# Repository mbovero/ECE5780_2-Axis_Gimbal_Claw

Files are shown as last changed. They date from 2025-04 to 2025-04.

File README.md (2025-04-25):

Demo

### Team Members
* Miles Bovero
* Lawrence Ponce
* Brian Stites
* Burke Dambly
  
# 2-Axis Gimbal System using BNO085 and TMC2209

This project implements a 2-axis gimbal system powered by NEMA 17 stepper motors, a custom TMC2209 stepper driver, and the BNO085 IMU, all controlled by an STM32F0 microcontroller. The system supports both **manual joystick control** and **automatic gimbal stabilization** using quaternion feedback from the IMU.

## Features

- **Automatic stabilization** using BNO085 quaternion output (Rotation Vector).
- **Manual override mode** via joystick input.
- **Custom driver logic** for TMC2209 stepper controllers (no libraries).
- **Status indication** using onboard LEDs:
  - 🟢 **Green**: System ready
  - 🟡 **Yellow**: Manual mode
  - 🔴 **Red**: Gimbal stabilization mode

## Hardware

- **Parts List:** https://docs.google.com/spreadsheets/d/1ASUmAiZSFDpc-IezaZOCM-j6GSmX4DIoBAKoNAnrK8I/edit?gid=0#gid=0
- **BOM:** https://docs.google.com/spreadsheets/d/1F1Fa0VNCSiJDzJphaV6HfyEmqR7Gyjhc7J4WnCEqq48/edit?usp=sharing

## Control Logic

- System starts in **gimbal mode**. The initial orientation is stored as the target.
- A joystick button press toggles between **manual** and **gimbal** mode.
- In **manual mode**, the joystick directly sets direction and speed of the motors.
- In **gimbal mode**, real-time quaternion feedback from the IMU drives motors to minimize roll and yaw error.
- The STM32 blue on-board button acts as a **kill switch**, freezing the system until reset.

## Project Structure

- `main.c` – Main call to control function.
- `bno085.c/h` – IMU I2C interface and quaternion parsing logic.
- `motor_control.c/h` – Low-level motor driver setup and PWM control.
- `quaternion.c/h` – Roll and yaw error computation from quaternion deltas.
- `gimbal_controller.c/h` – Core application logic for managing gimbal behavior, mode switching, LED indicators, and overall control flow between manual and automatic stabilization.
- `joystick.c/h` – ADC interface for reading joystick analog input.

## Flow Chart
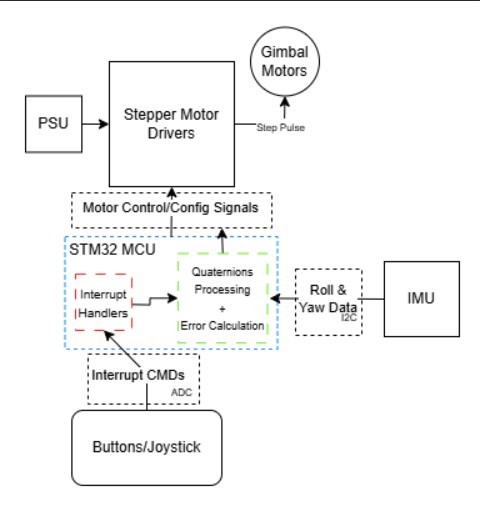
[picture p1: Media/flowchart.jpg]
Functional Diagram


## Capabilities

- Real-time stabilization on **roll and yaw axes** using quaternion feedback from the BNO085 IMU.
- Responsive **manual control** through a 2-axis joystick.
- Intelligent speed scaling and jitter prevention based on calculated orientation error.
- Mode switching with software debouncing: easily toggle between manual and gimbal modes.
- Visual mode indication via red (manual) and yellow (gimbal) LEDs, and a green LED for system readiness.
- **Kill switch functionality** to safely disable the system at any time.

### Limitations

- The current mechanical setup limits **full-range roll rotation**. Due to the gimbal frame geometry, the roll axis cannot rotate completely while maintatining yaw logic without mechanical interference.
- All quaternion math is handled using **fixed-point arithmetic**, which prioritizes performance on the STM32F0 but limits precision.

## Setup

1. **Wiring:**
   - **Wiring Diagram:** https://drive.google.com/file/d/1Tr6oJw9C9LlnuBq3UyTGPtjXQ-eJ-zLg/view?usp=sharing
   - See Wiring section below for more details

2. **Flashing:**
   - Use Platformio in VS Code to Flash board.
   - Run `platformio run -e gimbal_controller -t upload` in the Platformio terminal.

3. **Start Sequence:**
   - Wait for the **green LED** to turn on (IMU ready).
   - Press joystick button to toggle modes.
   - Use the kill switch (blue STM USER button) to halt the system if needed.

## 🔌 Wiring Connections
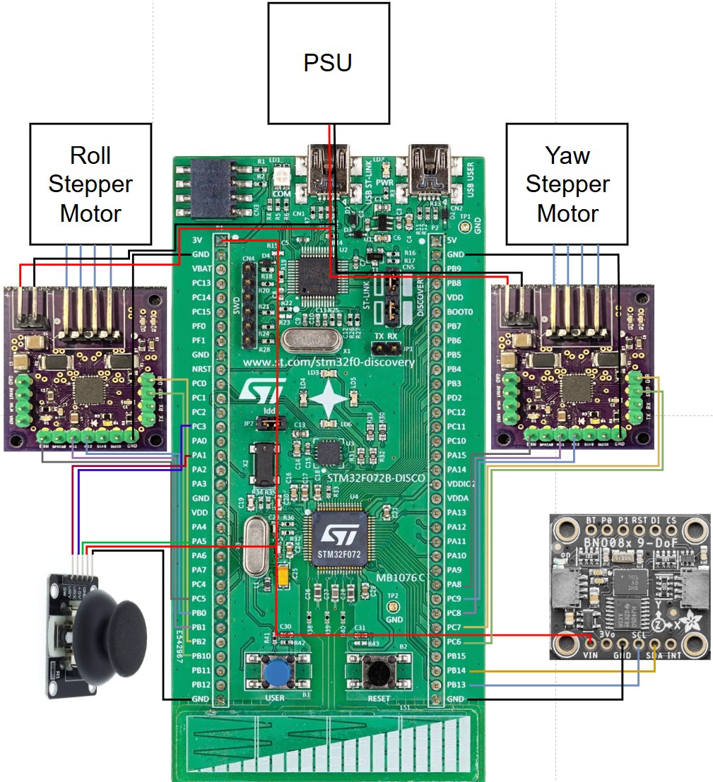
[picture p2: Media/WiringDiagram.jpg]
Wiring Diagram


### STM32 → IMU Wiring

| STM32 Pin | IMU Pin |
|---|---|
| 3V | 3V3 |
| GND | GND |
| PB14 | SDA / RX |
| PB13 | SCL / TX |

### STM32 → Motor Driver Wiring

#### YAW Motor Driver

| STM32 Pin | Motor Driver Pin |
|---|---|
| PC6 | STEP |
| PC7 | DIR |
| PC8 | MS1 |
| PC9 | MS2 |
| PA8 | ENN |
| GND | GND |

#### ROLL Motor Driver

| STM32 Pin | Motor Driver Pin |
|---|---|
| PB10 | STEP |
| PB2 | DIR |
| PB1 | MS1 |
| PB0 | MS2 |
| PC5 | ENN |
| GND | GND |

### STM32 → Joystick Wiring

| STM32 Pin | Joystick Pin |
|---|---|
| PC3 | VRY |
| PA5 | VRX |
| PA1 | SW |
| 3V | 5V |
| GND | GND |

### STM32 → LED Wiring

| STM32 Pin | Function |
|---|---|
| PB3 | IMU status LED |
| PB4 | Manual mode indicator LED  |
| PB5 | Gimbal mode indicator LED  |

## Notes
- Quaternion values are in **Q14 format** and processed using fixed-point arithmetic to avoid floating-point dependency.

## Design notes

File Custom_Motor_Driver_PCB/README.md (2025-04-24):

# PCB Layout Preview
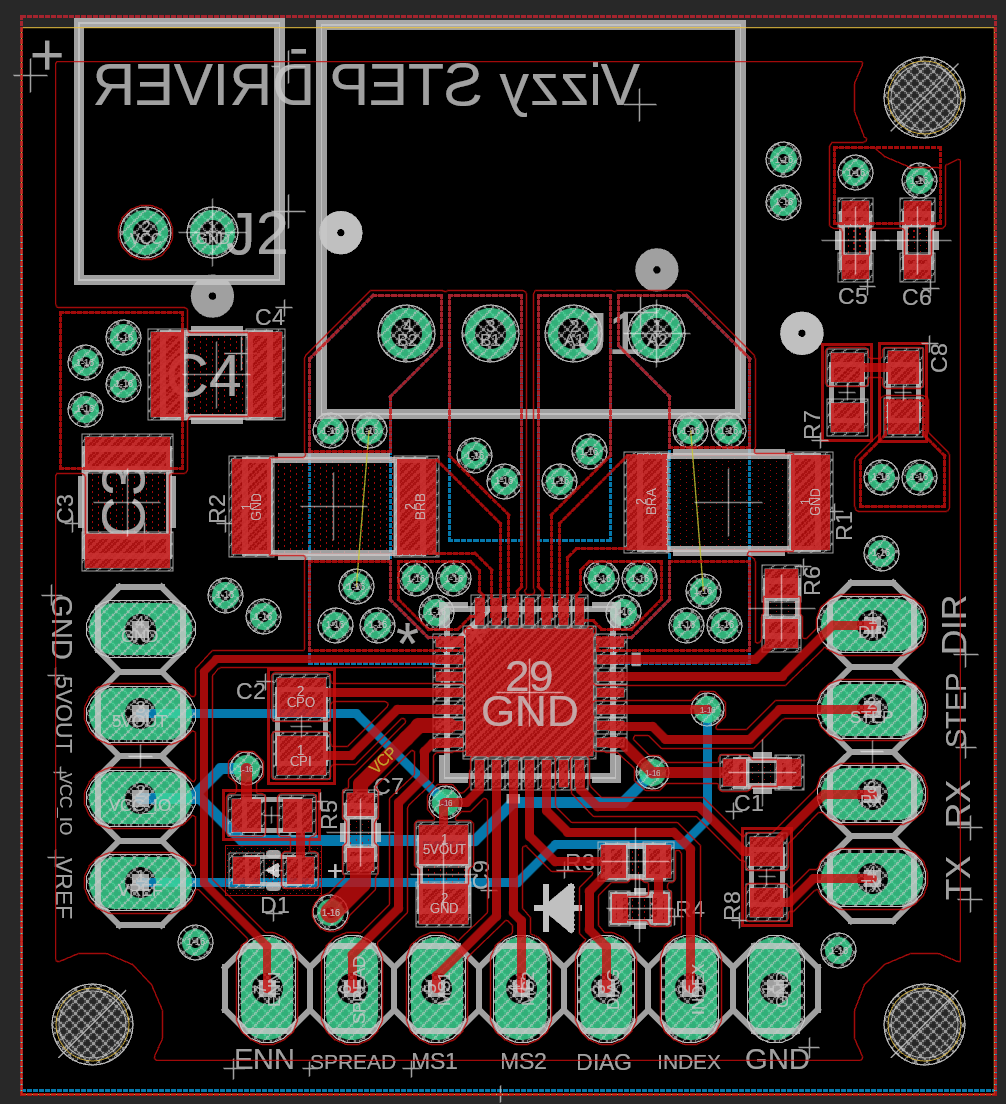
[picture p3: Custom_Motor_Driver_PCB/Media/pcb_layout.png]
PCB Layout Preview


# Circuit Schematic
[Circuit Schematic (PDF)](Media/circuit_schematic.pdf)

# 3D PCB Layout Preview
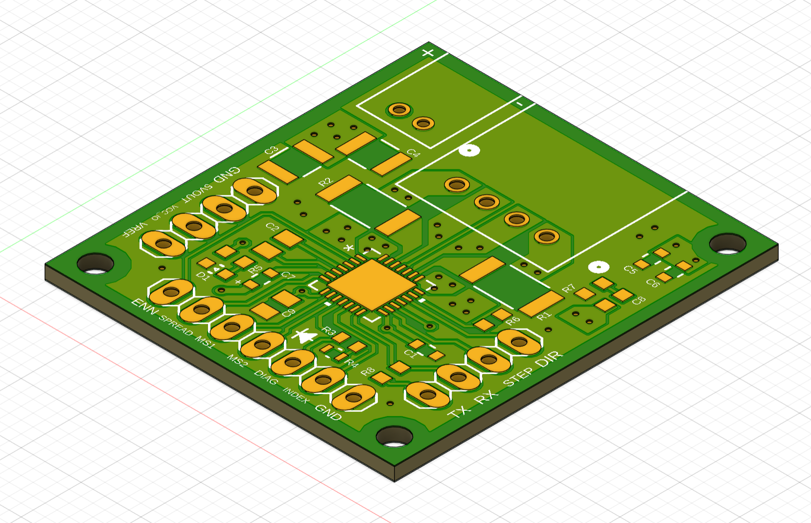
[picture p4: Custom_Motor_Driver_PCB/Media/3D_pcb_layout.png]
3D_PCB Layout Preview


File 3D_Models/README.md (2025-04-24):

# Upper Assembly Preview
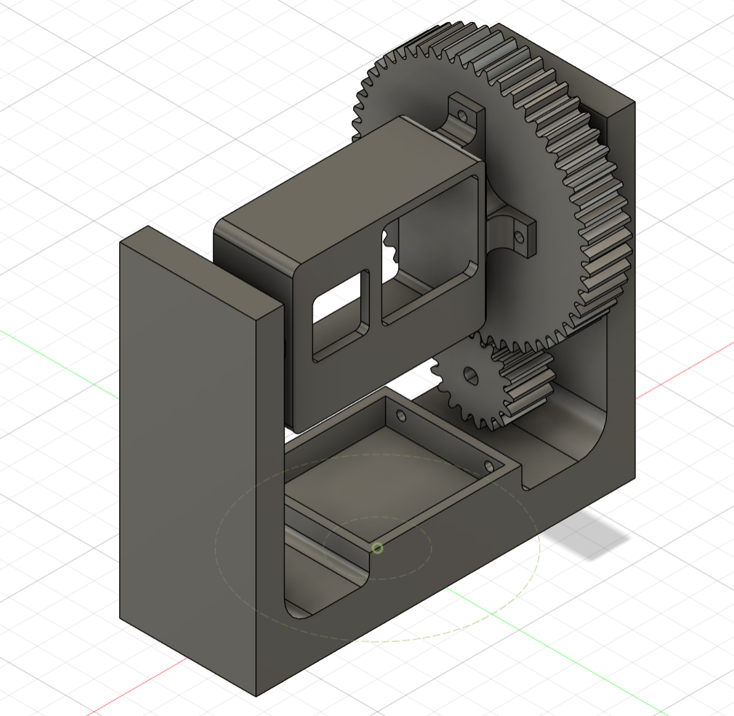
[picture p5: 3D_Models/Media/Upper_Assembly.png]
Upper Assembly


# Joystick Cage Preview
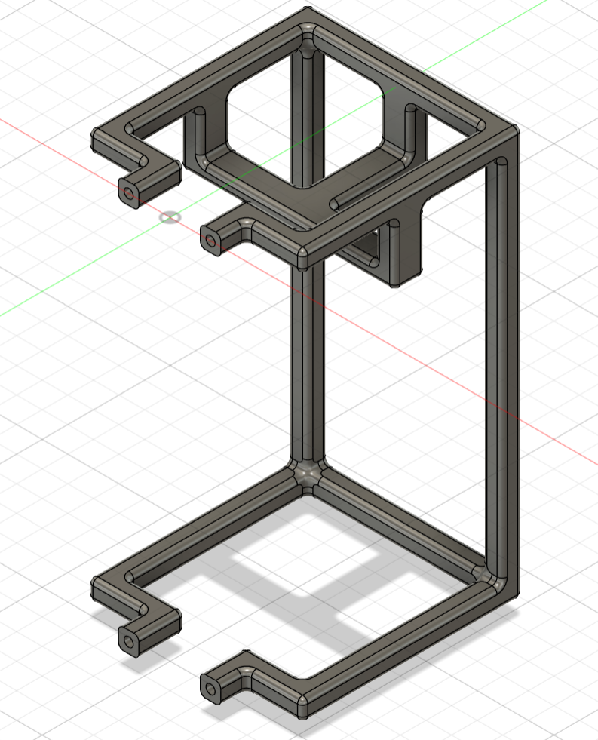
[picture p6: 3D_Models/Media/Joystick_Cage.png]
Joystick Cage


# Handle Preview
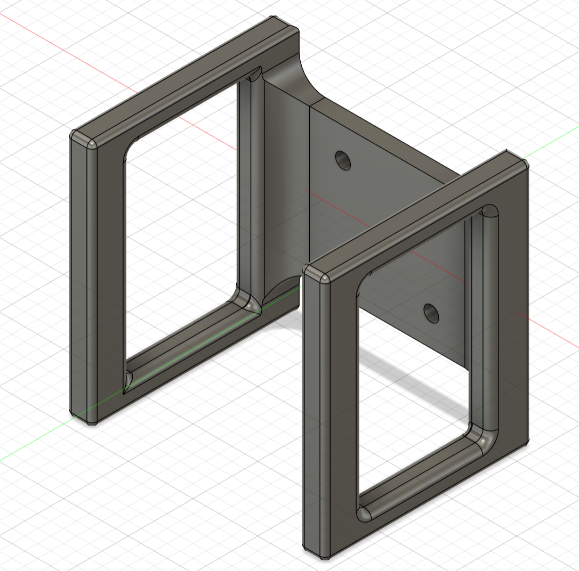
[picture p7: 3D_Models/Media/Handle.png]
Handle


# Gimbal Base Preview
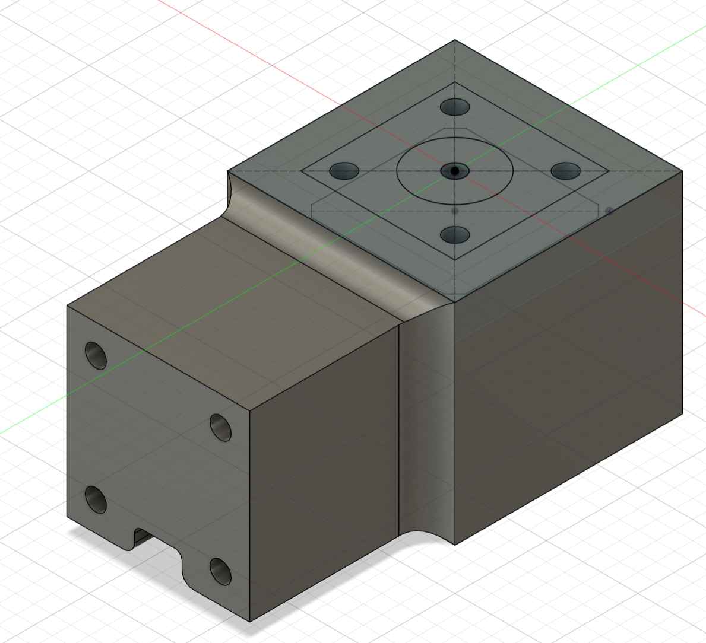
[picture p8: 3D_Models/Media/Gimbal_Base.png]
Gimbal_Base


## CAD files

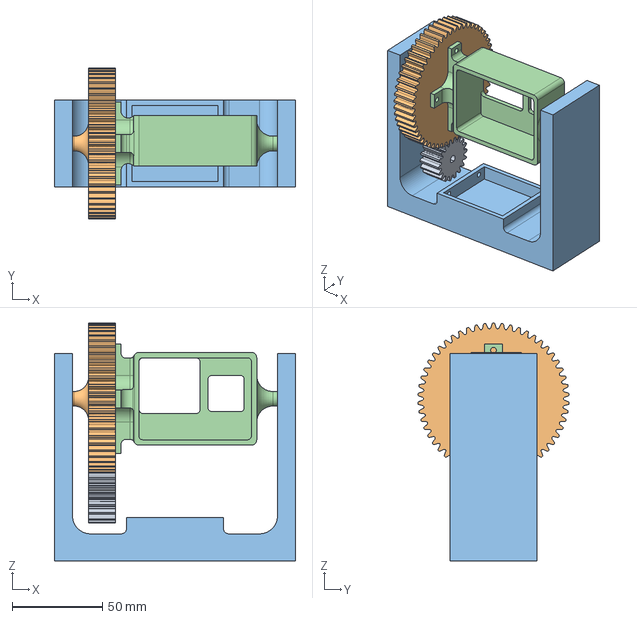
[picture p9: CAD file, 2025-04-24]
3D_Models/Upper Assembly v18.step
133.8 x 83.9 x 132.0 mm
Spur Gear (18 teeth)
Spur Gear (54 teeth)

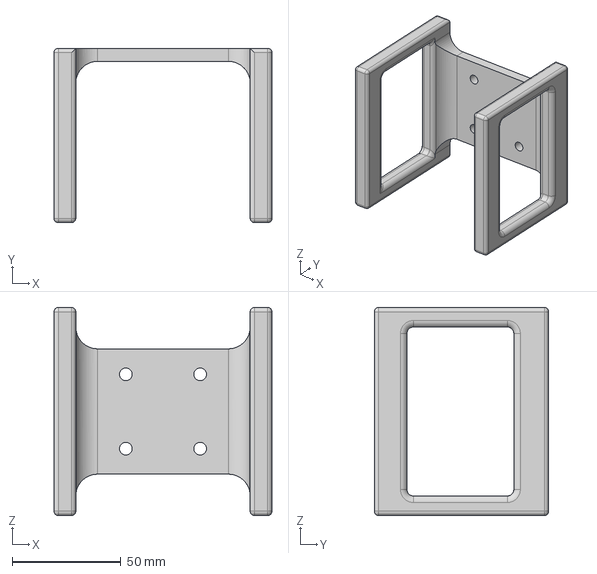
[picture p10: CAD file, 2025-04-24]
3D_Models/handle v4.step
100.0 x 80.0 x 95.5 mm

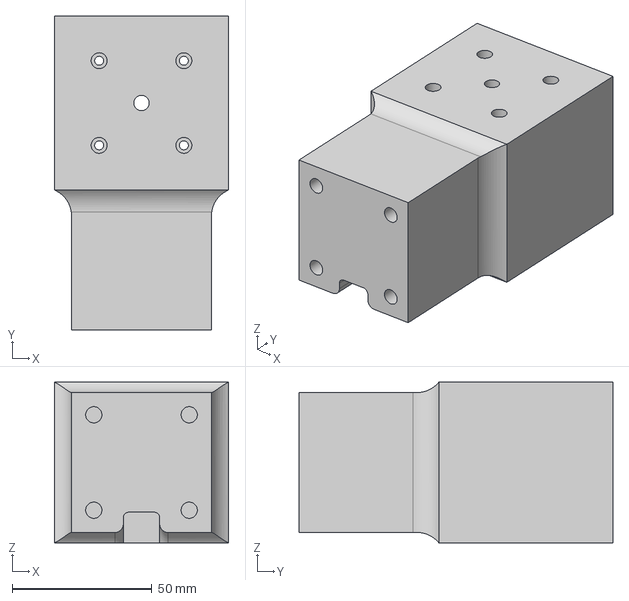
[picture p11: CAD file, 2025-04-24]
3D_Models/Gimbal Base v8.step
62.2 x 112.2 x 57.5 mm

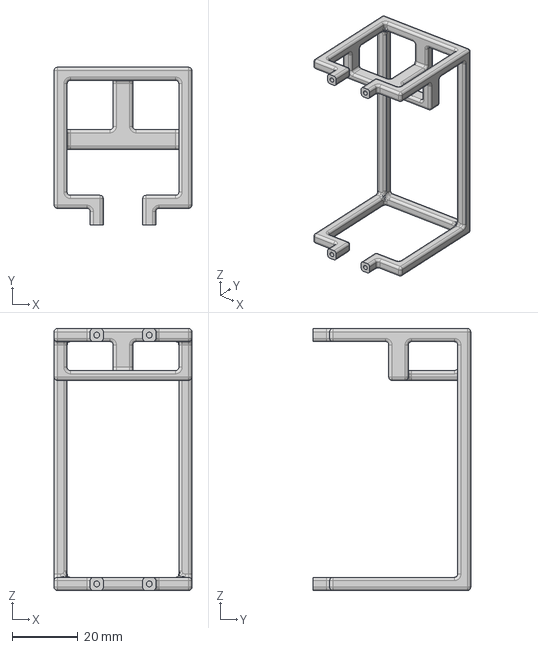
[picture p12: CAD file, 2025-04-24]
3D_Models/Joystick cage v3.step
42.0 x 48.0 x 79.8 mm

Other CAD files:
Custom_Motor_Driver_PCB/TMC2209_Circuit v29.f3z

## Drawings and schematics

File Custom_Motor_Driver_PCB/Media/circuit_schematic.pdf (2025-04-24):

GND | PINHD⁻¹X⁰⁷_1X⁰⁷M | PINHD⁻¹X⁰⁴_1X⁰⁴M
R8 | C9 J2

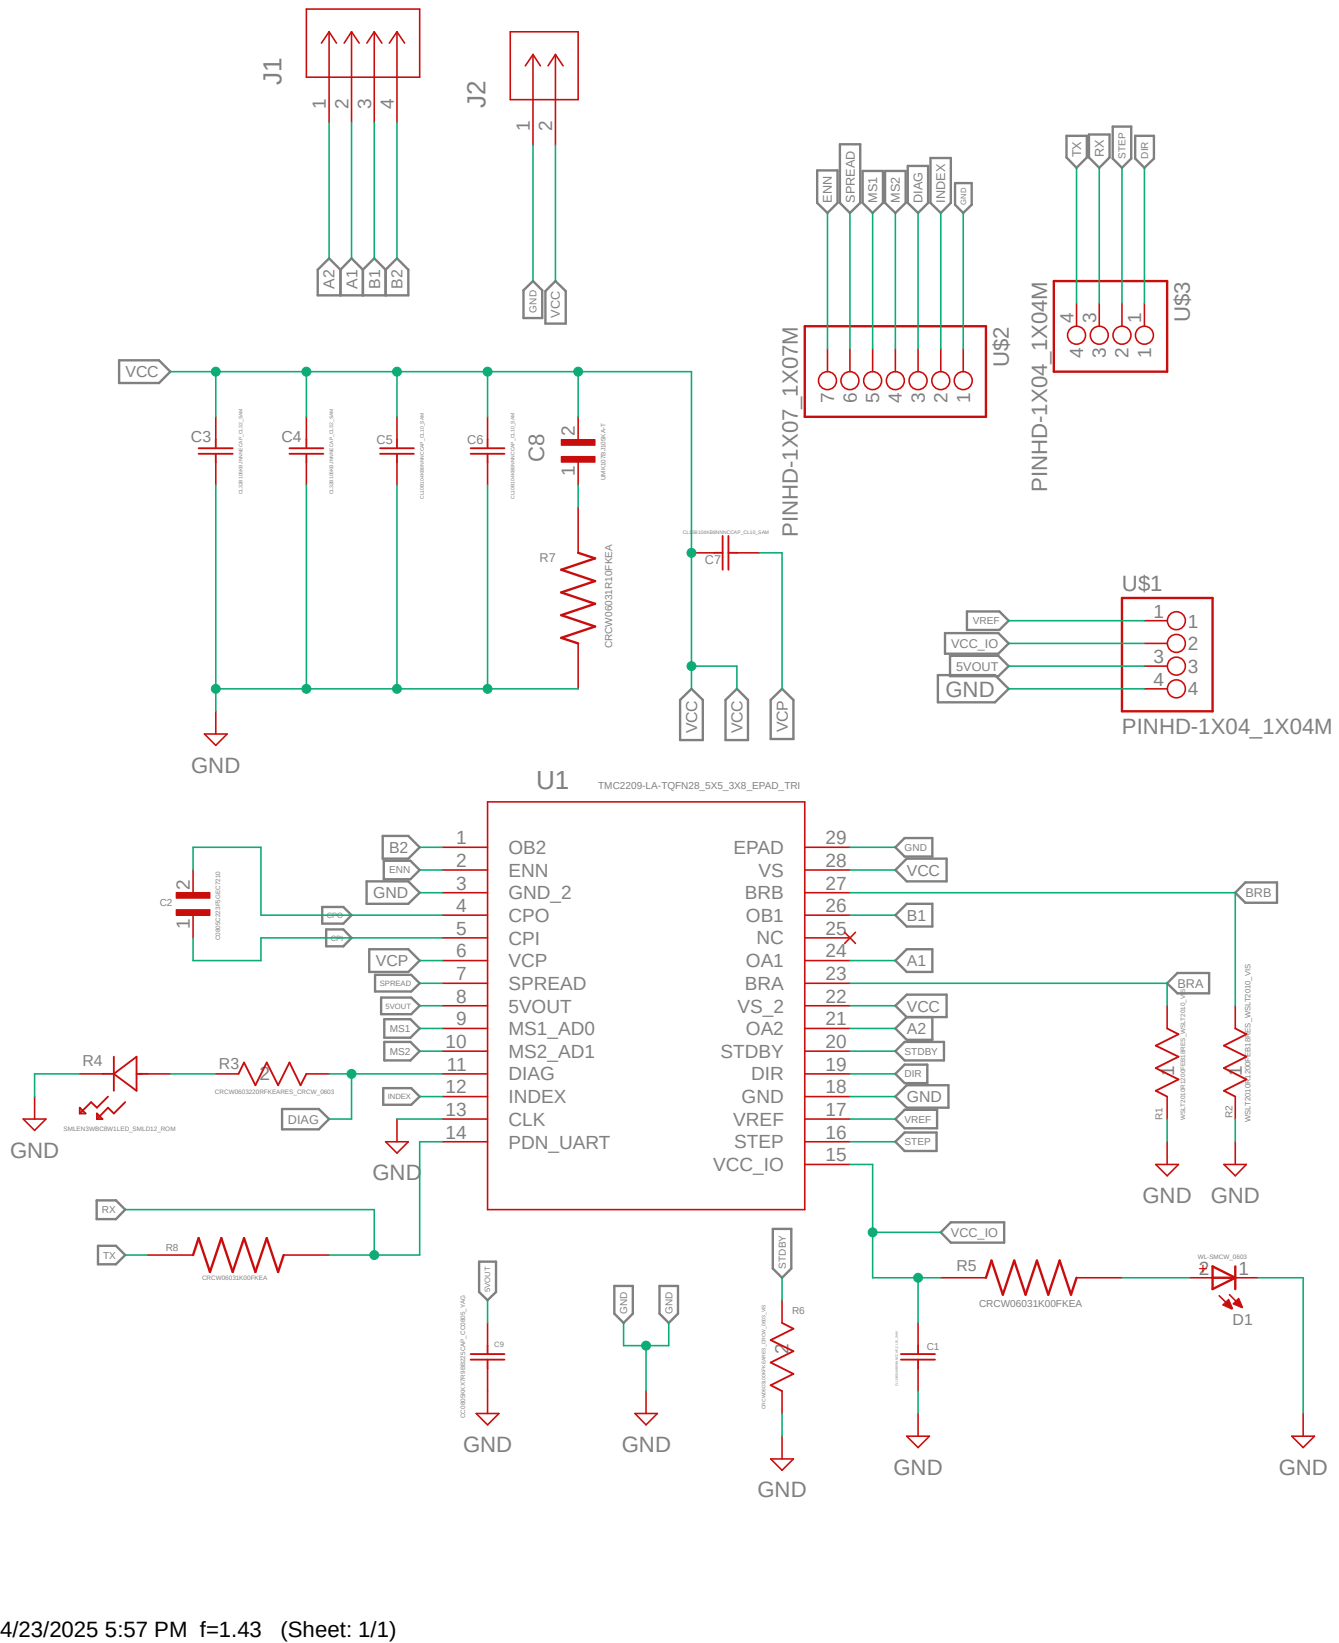
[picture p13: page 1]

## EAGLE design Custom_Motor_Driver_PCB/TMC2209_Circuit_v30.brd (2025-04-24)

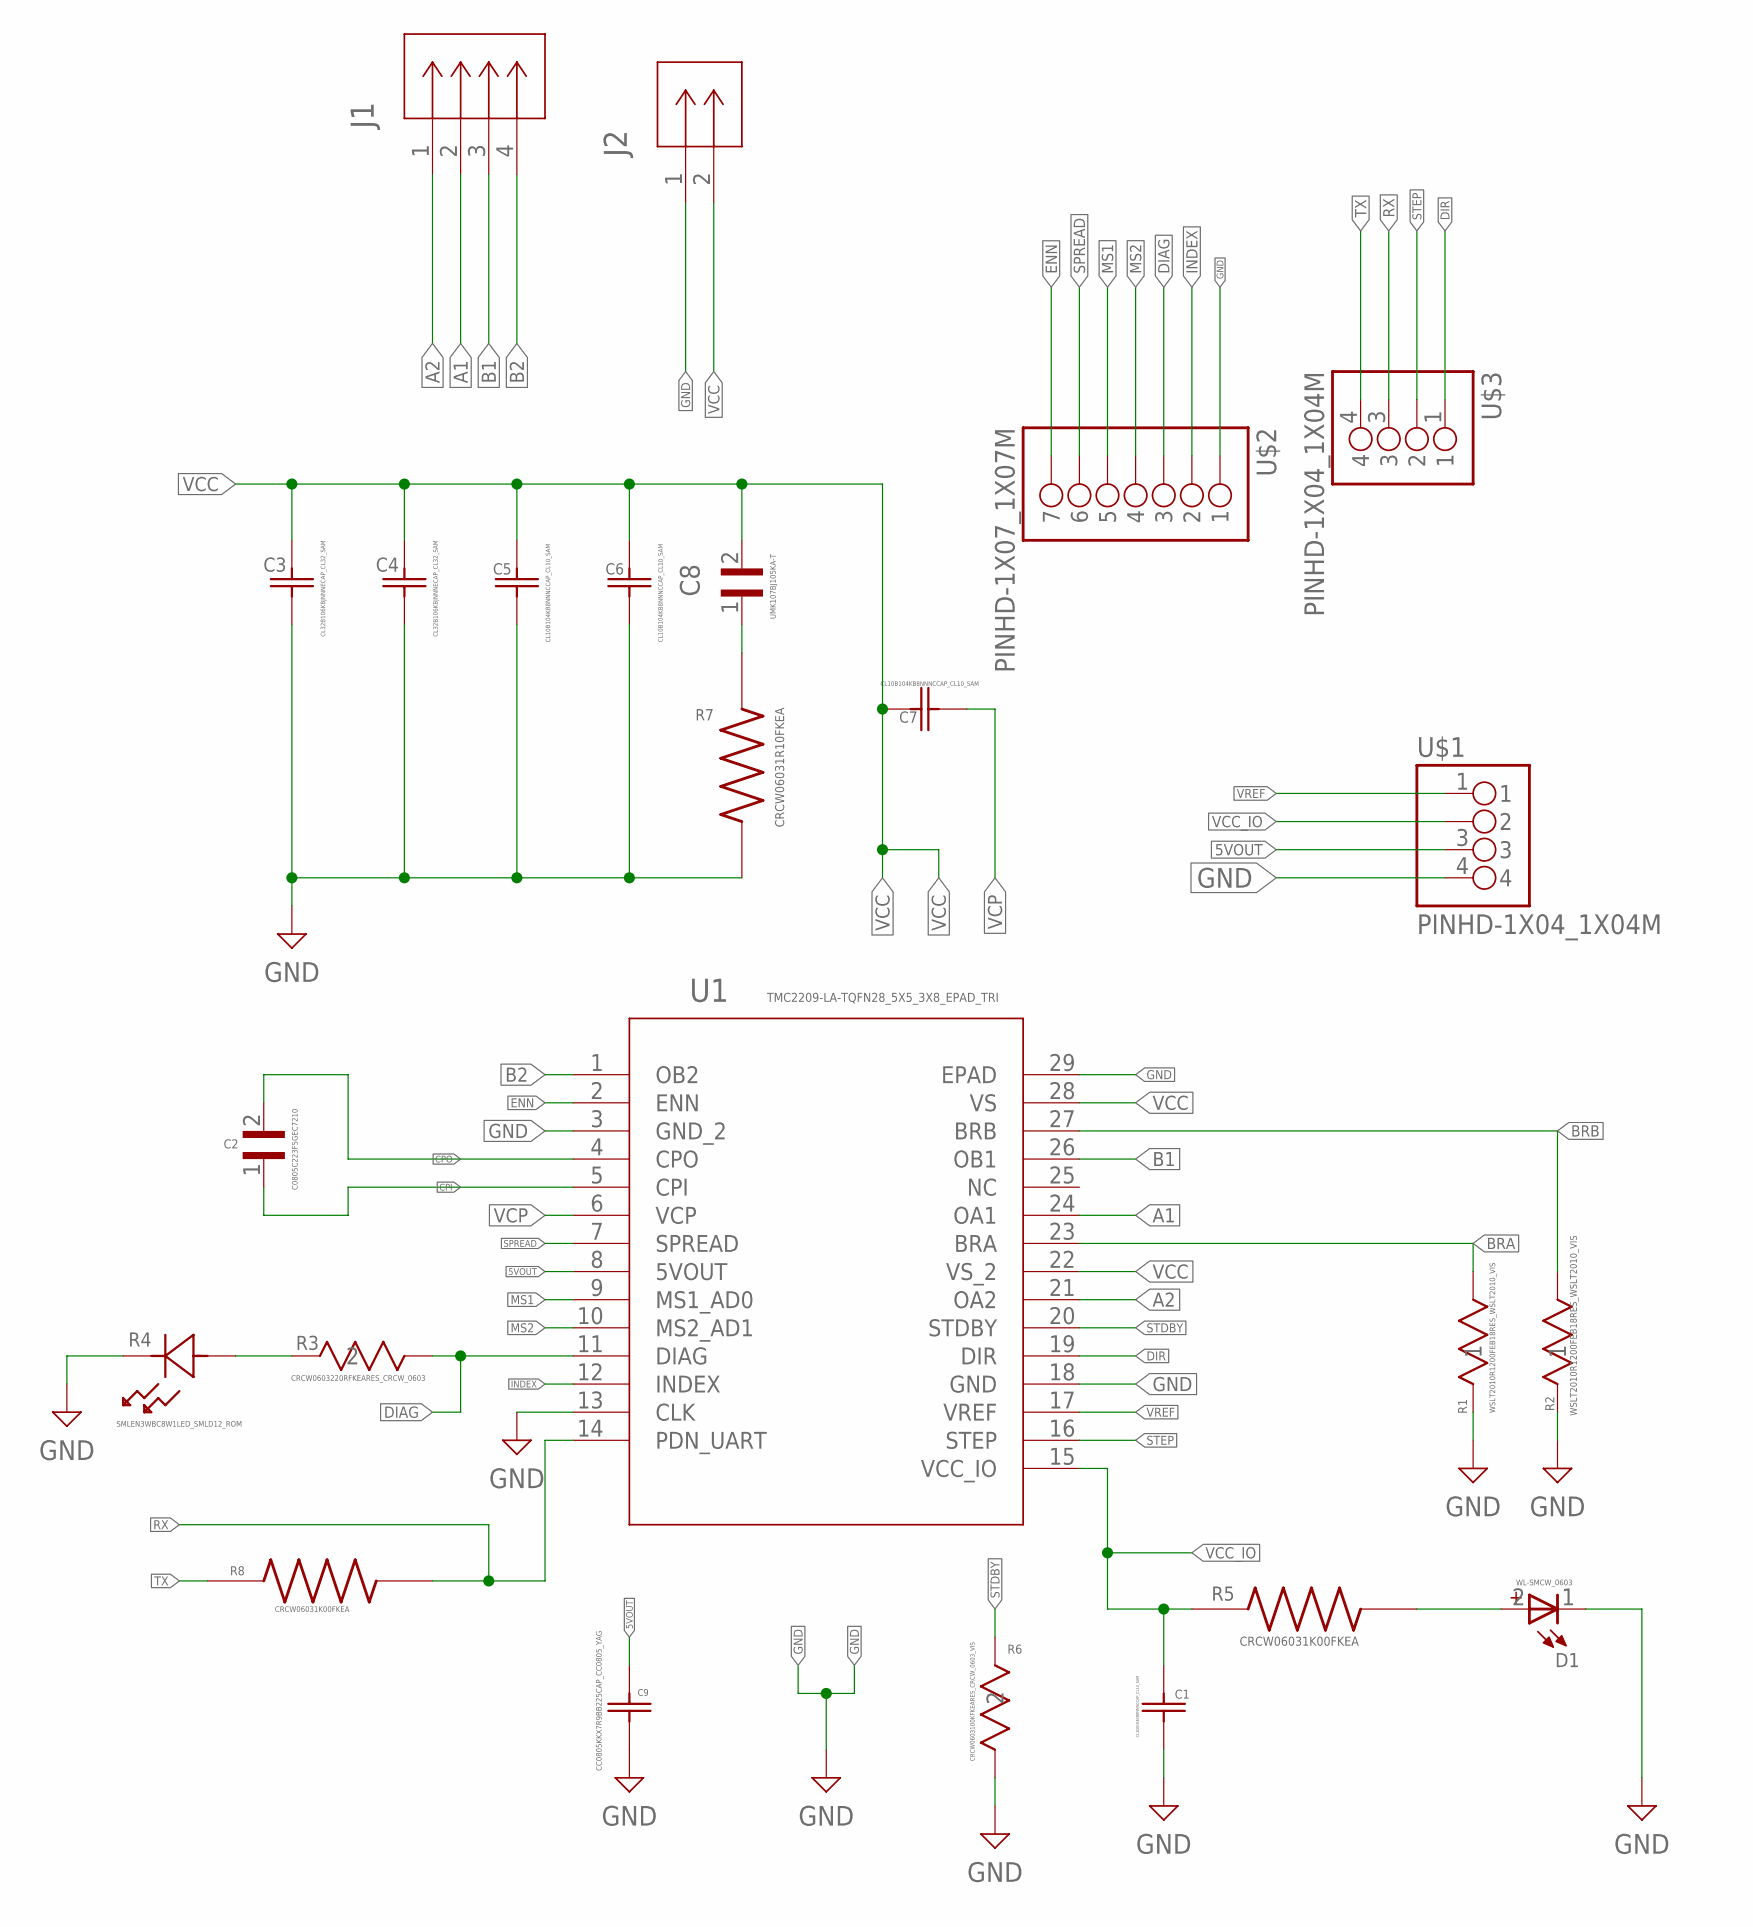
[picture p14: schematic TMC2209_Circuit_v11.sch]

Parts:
C1, C5, C6, C7: CL10B104KB8NNNCCAP_CL10_SAM; CAP_CL10_SAM
C2: C0805C223F5GEC7210; CAPC2012X120N
C3, C4: CL32B106KBJNNNECAP_CL32_SAM; CAP_CL32_SAM
C8: UMK107BJ105KA-T; CAPC1608X90N
C9: CC0805KKX7R9BB225CAP_CC0805_YAG; CAP_CC0805_YAG
D1: WL-SMCW_0603
J1: S4B-XH-A(LF)(SN)CONN_S4B-XH-A(LF)(SN)_JST; CONN_S4B-XH-A(LF)(SN)_JST
J2: S2B-PH-K-S(LF)(SN)CONN_S2B-PH-K-S_JST; CONN_S2B-PH-K-S_JST
R1, R2: WSLT2010R1200FEB18RES_WSLT2010_VIS; RES_WSLT2010_VIS
R3: CRCW0603220RFKEARES_CRCW_0603; RES_CRCW_0603
R4: SMLEN3WBC8W1LED_SMLD12_ROM; LED_SMLD12_ROM
R5, R8: CRCW06031K00FKEA; RESC1508X50N
R6: CRCW0603100KFKEARES_CRCW_0603_VIS; RES_CRCW_0603_VIS
R7: CRCW06031R10FKEA; RESC1508X50N
U1: TMC2209-LA-TQFN28_5X5_3X8_EPAD_TRI; QFN28_5X5_3X8_EPAD_TRI
U$1, U$3: PINHD-1X04_1X04M; 1X04
U$2: PINHD-1X07_1X07M; 1X07

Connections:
5VOUT: C9.1, U1.8 (5VOUT), U$1.3
A1: J1.2, U1.24 (OA1)
A2: J1.1, U1.21 (OA2)
B1: J1.3, U1.26 (OB1)
B2: J1.4, U1.1 (OB2)
BRA: R1.2, U1.23 (BRA)
BRB: R2.2, U1.27 (BRB)
CPI: C2.1, U1.5 (CPI)
CPO: C2.2, U1.4 (CPO)
DIAG: R3.1, U1.11 (DIAG), U$2.3
DIR: U1.19 (DIR), U$3.1
ENN: U1.2 (ENN), U$2.7
GND: C1.2, C3.1, C4.1, C5.1, C6.1, C9.2, D1.1 (-), J2.1, R1.1, R2.1, R4.1, R6.1, R7.1, U1.3 (GND_2), U1.13 (CLK), U1.18 (GND), U1.29 (EPAD), U$1.4, U$2.1
INDEX: U1.12 (INDEX), U$2.2
MS1: U1.9 (MS1_AD0), U$2.5
MS2: U1.10 (MS2_AD1), U$2.4
unnamed: R3.2, R4.2
unnamed: D1.2 (+), R5.2
unnamed: C8.1, R7.2
RX: R8.2, U1.14 (PDN_UART), U$3.3
SPREAD: U1.7 (SPREAD), U$2.6
STDBY: R6.2, U1.20 (STDBY)
STEP: U1.16 (STEP), U$3.2
TX: R8.1, U$3.4
VCC: C3.2, C4.2, C5.2, C6.2, C7.2, C8.2, J2.2, U1.22 (VS_2), U1.28 (VS)
VCC_IO: C1.1, R5.1, U1.15 (VCC_IO), U$1.2
VCP: C7.1, U1.6 (VCP)
VREF: U1.17 (VREF), U$1.1

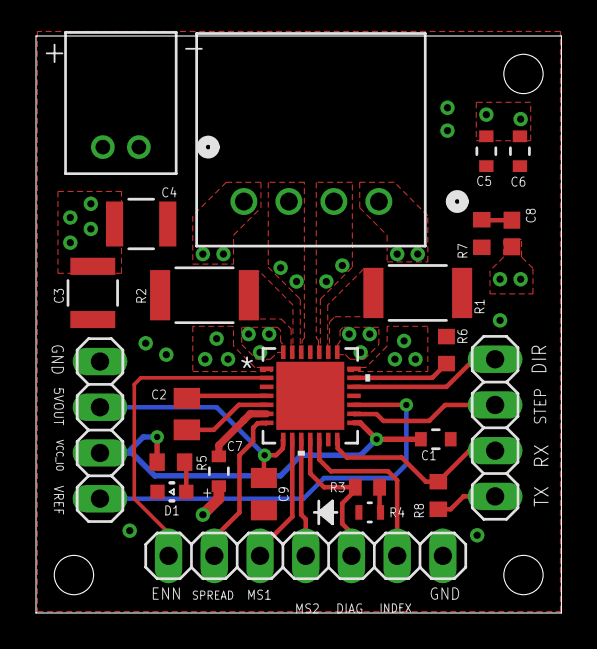
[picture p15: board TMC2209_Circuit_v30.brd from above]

Board: 4 copper layers, 29.2 x 32.1 mm, 24 parts (0 on the bottom side), 28 nets.

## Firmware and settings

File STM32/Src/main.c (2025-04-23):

#include "main.h"
#include <stm32f0xx_hal.h>

/**
 * Command  $ platformio run -e (name) -t upload
 * 
 * Go to platformio.ini file and add your file in the following format
 * [env:(file/custom name)]
 *  build_flags = -D(file/custom name)
 * 
 * The "(name)" is what you put inside the '[env:(name here)]'
 * 
 * Make sure to add your new file/function name to the main.h
 */
int main(void)
{
  #if defined(GIMBAL_CONTROLLER)
  gimbal_controller();


  /*
  #elif defined(othername)
  lab2_main();
 */
  #else
  #error No valid target specified
  #endif

}

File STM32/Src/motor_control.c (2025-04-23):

#include "motor_control.h"
#include "config.h"
#include <math.h>

/**
 * @brief Initializes GPIO pins and timers for roll and yaw motor control.
 * 
 * Configures direction, microstepping, enable, and step pins for both motor drivers.
 * Sets up TIM2 and TIM3 to generate PWM signals with 50% duty cycle for motor stepping.
 */
void motor_init()
{
    // Enable GPIO and TIM clocks
    __HAL_RCC_GPIOA_CLK_ENABLE();
    __HAL_RCC_GPIOC_CLK_ENABLE();
    __HAL_RCC_GPIOB_CLK_ENABLE();
    __HAL_RCC_TIM2_CLK_ENABLE();
    __HAL_RCC_TIM3_CLK_ENABLE();
    
    // --- YAW MOTOR INITIALIZATION ---

    // Configure PC6 (STEP) for PWM (TIM3_CH1)
    GPIO_InitTypeDef GPIO_InitStructPWM = {GPIO_PIN_6, 
                                            GPIO_MODE_AF_PP, 
                                            GPIO_NOPULL, 
                                            GPIO_SPEED_FREQ_LOW, 
                                            GPIO_AF0_TIM3};
    HAL_GPIO_Init(GPIOC, &GPIO_InitStructPWM);

    // Configure PC7 (DIR), PC8 (MS1), PC9 (MS2) as digital outputs
    GPIO_InitTypeDef GPIO_InitStructDIO1 = {GPIO_PIN_7 | GPIO_PIN_8 | GPIO_PIN_9, 
                                            GPIO_MODE_OUTPUT_PP, 
                                            GPIO_NOPULL, 
                                            GPIO_SPEED_FREQ_LOW};
    HAL_GPIO_Init(GPIOC, &GPIO_InitStructDIO1);

    // Configure PA8 (ENN) as a digital output
    GPIO_InitTypeDef GPIO_InitStructDIO2 = {GPIO_PIN_8, 
                                            GPIO_MODE_OUTPUT_PP, 
                                            GPIO_PULLDOWN, 
                                            GPIO_SPEED_FREQ_LOW};
    HAL_GPIO_Init(GPIOA, &GPIO_InitStructDIO2);

    

    // Timer3 PWM bitwise setup for PC6
    TIM3->PSC = 99; // Timer clock freq = 8MHz/(PSC+1) 
    TIM3->ARR = 79; // Set timer reload value
    // PWM Mode1 on CH1, preload enable
    TIM3->CCMR1 &= ~TIM_CCMR1_OC1M;
    TIM3->CCMR1 |= (6 << TIM_CCMR1_OC1M_Pos) | TIM_CCMR1_OC1PE;
    // 50% duty: CCR1 = (ARR+1)/2
    TIM3->CCR1 = (TIM3->ARR + 1) >> 1;
    // Enable CH1 output, start counter
    TIM3->CR1 |= 1;
    

    // Set initial outputs to motor driver
        // MS2, MS1 = 1,0: 1/64 microstep resolution
    HAL_GPIO_WritePin(GPIOC, GPIO_PIN_9, GPIO_PIN_SET);     // MS2: 1   
    HAL_GPIO_WritePin(GPIOC, GPIO_PIN_8, GPIO_PIN_RESET);   // MS1: 0
    HAL_GPIO_WritePin(GPIOA, GPIO_PIN_8, GPIO_PIN_RESET);   // ENN: 0
    HAL_GPIO_WritePin(GPIOC, GPIO_PIN_7, GPIO_PIN_SET);     // DIR: 1


    // --- ROLL MOTOR INITIALIZATION ---
    // Configure PB10 (STEP) for PWM (TIM2_CH3)
    GPIO_InitTypeDef GPIO_InitStructPWM2 = {GPIO_PIN_10, 
                                            GPIO_MODE_AF_PP, 
                                            GPIO_NOPULL, 
                                            GPIO_SPEED_FREQ_LOW, 
                                            GPIO_AF2_TIM2};
    HAL_GPIO_Init(GPIOB, &GPIO_InitStructPWM2);

    // Configure PB2 (DIR), PB1 (MS1), PB0 (MS2) as digital outputs
    GPIO_InitTypeDef GPIO_InitStructDIO3 = {GPIO_PIN_2 | GPIO_PIN_1 | GPIO_PIN_0, 
            GPIO_MODE_OUTPUT_PP, 
            GPIO_NOPULL, 
            GPIO_SPEED_FREQ_LOW};
    HAL_GPIO_Init(GPIOB, &GPIO_InitStructDIO3);

    // Configure PC5 (ENN) as a digital output
    GPIO_InitTypeDef GPIO_InitStructDIO4 = {GPIO_PIN_5, 
            GPIO_MODE_OUTPUT_PP, 
            GPIO_PULLDOWN, 
            GPIO_SPEED_FREQ_LOW};
    HAL_GPIO_Init(GPIOC, &GPIO_InitStructDIO4);


    // Timer2 PWM bitwise setup for PB10
    TIM2->PSC = 49; // timer clock freq = 8MHz/(PSC+1) 
    TIM2->ARR = 79; // Set timer reload value
    // PWM Mode1 on CH3, preload enable
    TIM2->CCMR2 &= ~TIM_CCMR1_OC1M;
    TIM2->CCMR2 |= (6 << TIM_CCMR2_OC3M_Pos) | TIM_CCMR2_OC3PE;
    // 50% duty: CCR3 = (ARR+1)/2
    TIM2->CCR3 = (TIM2->ARR + 1) >> 1;
    // Enable CH3 output, start counter
    TIM2->CR1 |= 1;


    // Set initial outputs to motor driver
        // MS2, MS1 = 1,0: 1/64 microstep resolution
    HAL_GPIO_WritePin(GPIOC, GPIO_PIN_0, GPIO_PIN_SET);     // MS2: 1
    HAL_GPIO_WritePin(GPIOC, GPIO_PIN_1, GPIO_PIN_RESET);   // MS1: 0   
    HAL_GPIO_WritePin(GPIOA, GPIO_PIN_5, GPIO_PIN_RESET);   // ENN: 0
    HAL_GPIO_WritePin(GPIOC, GPIO_PIN_2, GPIO_PIN_SET);     // DIR: 1
}

/**
 * @brief Sets roll motor speed and direction based on gimbal mode error.
 * 
 * Adjusts motor speed by changing TIM2 prescaler based on the magnitude of the roll error.
 * Determines motor direction from the sign of the error.
 * Stops the motor if the error is below a threshold to prevent jitter.
 * 
 * @param err_roll Signed roll error from gimbal control algorithm.
 */
void roll_motor_set_speed_dir_gimbal(int16_t err_roll)
{
    // Dynamically adjust motor speed based on roll error
    if(abs(err_roll) >= 3000)
    { 
        TIM2->PSC = 39;
    }
    else if(abs(err_roll) >= 2500)
    { 
        TIM2->PSC = 49;
    }
    else if(abs(err_roll) >= 2000)
    { 
        TIM2->PSC = 59;
    }
    else if(abs(err_roll) >= 1500)
    { 
        TIM2->PSC = 69;
    }
    else if(abs(err_roll) >= 1000)
    { 
        TIM2->PSC = 79;
    }
    else if(abs(err_roll) >= 700)
    { 
        TIM2->PSC = 99;
    }
    else if(abs(err_roll) >= 500)
    { 
        TIM2->PSC = 149;
    }
    else if(abs(err_roll) >= 300)
    { 
        TIM2->PSC = 249;
    }
    else if(abs(err_roll) >= 200)
    { 
        TIM2->PSC = 349;
    }

    // When above a minimum threshold, set motor direction based on sign of roll error
    if (abs(err_roll) >= 100)
    {
        (err_roll > 0) ? roll_motor_set_dir(0) : roll_motor_set_dir(1);
        roll_motor_resume();
    }
    else    // When below minimum threshold, stop motors to prevent jitter
    {   
        roll_motor_stop();
    }
}

/**
 * @brief Sets roll motor speed and direction based on joystick input in manual mode.
 * 
 * Interprets joystick vertical input (vry) as speed and direction for the roll motor.
 * Adjusts TIM2 prescaler to change speed based on deviation from center position (70).
 * Stops the motor if input is near center to avoid unwanted movement.
 * 
 * @param vry Vertical joystick input (0–140 range expected, with ~70 as center).
 */
void roll_motor_set_speed_dir_manual(uint8_t vry)
{
    // Dynamically adjust motor speed based on vertical joystick input
    if(abs(vry-70) >= 60)
    { 
        TIM2->PSC = 40;
    }
    else if(abs(vry-70) >= 40)
    { 
        TIM2->PSC = 70;
    }

    // When above a minimum threshold, set motor direction based on sign of vertical joystick input
    if (abs(vry-70) >= 30)
    {
        (vry-70 > 0) ? roll_motor_set_dir(0) : roll_motor_set_dir(1);
        roll_motor_resume();
    }
    else    // When below minimum threshold, stop motors to prevent jitter
    {   
        roll_motor_stop();
    }
}
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

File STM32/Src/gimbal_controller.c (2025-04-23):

#include <stm32f0xx_hal.h>
#include "main.h"
#include "bno085.h"
#include "motor_control.h"
#include "quaternion.h"
#include "config.h"
#include "joystick.h"

// Parsed and Q14-formatted quaternion data representing TARGET orientation
volatile int16_t ti, tj, tk, tr;    

// Parsed and Q14-formatted quaternion data representing CURRENT orientation
volatile int16_t ci, cj, ck, cr;

// I2C handle for I2C2
I2C_HandleTypeDef hi2c2;

// Status bit indicating current gimbal mode
volatile uint8_t manual_control = 0;    // System starts in gimbal mode by default

/**
 * @brief  Main control loop for managing the gimbal system.
 *
 * This function handles both manual and automatic (gimbal mode) operation of the gimbal. 
 * It initializes necessary peripherals, including motor control, IMU (BNO085), joystick interface, 
 * and LED indicators. The function continuously reads joystick input for manual control or IMU data 
 * for gimbal mode, calculates orientation errors, and adjusts motor movement to stabilize the gimbal.
 * 
 * In manual mode, the joystick directly controls motor movement. In gimbal mode, the system reads 
 * quaternion data from the IMU, computes errors in the system’s orientation, and adjusts motor speed 
 * and direction to minimize these errors.
 * 
 * @retval None
 */
int gimbal_controller(void)
{
    HAL_Init();                  // Initialize HAL
    motor_init();                // Initialize GPIO pins and peripherals for motor control
    stm_bno085_i2c_init(&hi2c2); // Initialize GPIO pins and peripherals for IMU communication
    bno085_init(&hi2c2);         // Reset, initialize, and configure the IMU
    joystick_init();             // Initialize GPIO pins and peripherals for joystick interface

    
    // Initialize PB4 as manual mode LED indicator and PB5 as gimbal mode LED indicator
    __HAL_RCC_GPIOB_CLK_ENABLE();
    GPIO_InitTypeDef initStrPB4_5 = {GPIO_PIN_4 | GPIO_PIN_5, GPIO_MODE_OUTPUT_PP, GPIO_NOPULL, GPIO_SPEED_FREQ_LOW};
    HAL_GPIO_Init(GPIOB, &initStrPB4_5);

    // Initialize PA0 (USER Button) as system kill switch
    __HAL_RCC_GPIOA_CLK_ENABLE();
    GPIO_InitTypeDef initStrPA0 = {GPIO_PIN_0,
                                    GPIO_MODE_INPUT,
                                    GPIO_PULLDOWN,
                                    GPIO_SPEED_FREQ_LOW};
    HAL_GPIO_Init(GPIOA, &initStrPA0);

    // Configure PA0 for EXTI0
    __HAL_RCC_SYSCFG_CLK_ENABLE();
    SYSCFG->EXTICR[0] &= ~(0xF);        // Set EXTI0 output to PA0
    EXTI->IMR |= EXTI_IMR_IM0;          // Enable interrupts on line 0
    EXTI->RTSR |= EXTI_RTSR_TR0;        // Enable rising edge trigger for line 0
    NVIC_EnableIRQ(EXTI0_1_IRQn);       // Enable EXTI0 interrupt
    NVIC_SetPriority(EXTI0_1_IRQn, 0);  // Set priority for EXTI0 to 0 (highest-priority)

    void EXTI0_1_IRQHandler();  // Declare handler for interrupts on lines 0 and 1



    // Use initial IMU rotation vector as target orientation
    bno085_read_rotation_vector(&hi2c2, &ci, &cj, &ck, &cr);
    ti = ci;
    tj = cj;
    tk = ck;
    tr = cr;

    // Turn on LED indicator for gimbal mode
    HAL_GPIO_WritePin(GPIOB, GPIO_PIN_5, GPIO_PIN_SET);


    // Main while loop
    while (1)
    {
        if (manual_control)     // Manual mode (joystick control)
        {
            // Continue reading from IMU to keep rotation vector quaternion data buffer clear
            bno085_read_rotation_vector(&hi2c2, &ci, &cj, &ck, &cr);

            // Read analog joystick inputs
            uint8_t vrx, vry;
            joystick_read_vrx_vry(&vrx, &vry);

            // Change motors' speed and direction based on joystick inputs
            roll_motor_set_speed_dir_manual(vry);
            yaw_motor_set_speed_dir_manual(vrx);
        }
        else    // Gimbal Mode
        {   
            // Attempt to read quaternion data from IMU
            if (bno085_read_rotation_vector(&hi2c2, &ci, &cj, &ck, &cr))
            {
                // If communication fails, stop rotating motors to prevent damage to system
                roll_motor_stop();
                yaw_motor_stop();
                continue;
            }

            // Compute errors for roll and yaw axes
            int16_t err_roll  = compute_roll_error(cr, ci, cj, ck, tr, ti, tj, tk);
            int16_t err_yaw   = compute_yaw_error(cr, ci, cj, ck, tr, ti, tj, tk);

            // Change motors' speed and direction based on calculated error
            roll_motor_set_speed_dir_gimbal(err_roll);
            yaw_motor_set_speed_dir_gimbal(err_yaw);
            
            HAL_Delay(2);
        }
    }
}

/**
 * @brief  External interrupt handler for EXTI lines 0 and 1.
 * 
 * Handles two types of events:
 * - EXTI1 (PA1 - Joystick button): Toggles between manual and gimbal control modes with debouncing.
 * - EXTI0 (PA0 - User button): Acts as a kill switch to halt the system indefinitely.
 * 
 * Updates LED indicators accordingly and ensures safe motor control transitions.
 */
void EXTI0_1_IRQHandler()
{
    // Initialize variables for button debouncing
    static uint32_t last_interrupt_time_pa1 = 0;
    static uint32_t last_interrupt_time_pa0 = 0;
    uint32_t current_time = HAL_GetTick();

    // Check EXTI1 (PA1 Joystick Button)
    if (EXTI->PR & EXTI_PR_PR1) 
    {
        EXTI->PR |= EXTI_PR_PR1; // Clear pending flag

        if (current_time - last_interrupt_time_pa1 > 200) // Debouncing
        {
            last_interrupt_time_pa1 = current_time;

            // Toggle operation mode (gimbal <--> manual)
            manual_control = !manual_control;

            if (!manual_control) 
            {
                // When transitioning from manual mode to gimbal mode, update target orientation
                ti = ci;
                tj = cj;
                tk = ck;
                tr = cr;
                
                // Disable manual mode LED indicator, and enable gimbal mode LED indicator
                HAL_GPIO_WritePin(GPIOB, GPIO_PIN_4, GPIO_PIN_RESET);
                HAL_GPIO_WritePin(GPIOB, GPIO_PIN_5, GPIO_PIN_SET);
            } else 
            {
                // Enable manual mode LED indicator, and disable gimbal mode LED indicator
                HAL_GPIO_WritePin(GPIOB, GPIO_PIN_4, GPIO_PIN_SET);
                HAL_GPIO_WritePin(GPIOB, GPIO_PIN_5, GPIO_PIN_RESET);
            }
        }
    }


    // Check EXTI0 (PA0 User Button kill switch)
    if (EXTI->PR & EXTI_PR_PR0) 
    {
        EXTI->PR |= EXTI_PR_PR0; // Clear pending flag

        if (current_time - last_interrupt_time_pa0 > 200)   // Debouncing
        {
            last_interrupt_time_pa0 = current_time;

            // Stop all motors
            roll_motor_stop();
            yaw_motor_stop();

            // Stop the system forever (system reset required to resume)
            while (1);
        }
    }
}

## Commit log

2025-03-22 Added STM32 Infrastructure
2025-03-23 red led on PWM with flux duty cycle
2025-03-23 Wrote GPIO and register initialization code for I2C communication
2025-03-24 Configured timer channel 1 on tim3, tim16, and tim17 to output a pwm signal, experimentation is needed on variable speeds/switching directions while fully enabled
2025-03-24 Successfully receiving rotation vector data over I2C
2025-04-05 Implemented I2C/SHTP read and write functions for IMU communication
2025-04-06 Established connection with IMU using custom functions
2025-04-06 Generated LED ouputs based on IMU rotation
2025-04-06 Completed first gimbal system proof-of-concept using LEDs
2025-04-17 Troubleshooting motor driver
2025-04-18 test code for stepper driver in imu_i2c test file
2025-04-19 Experimented with dynamic motor control via IMU
2025-04-19 Changed signals for motor testing
2025-04-22 Working gimbal code with reset interrupt
    [bno085.c, gimbal_controller.c, main.c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]
2025-04-22 joystick motor control working
2025-04-23 Removed unused functions and added new functions for manual (joystick) motor control
2025-04-23 Performed final code cleanup: fixed/improved commenting, added function headers, removed unnecessary or dead code
    [bno085.c, gimbal_controller.c, joystick.c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]
2025-04-23 Fixed GPIO pin comments regarding ADC inputs
    [joystick.c]
2025-04-24 Uploaded custom stepper motor driver files
    [TMC2209_Circuit v29.f3z, TMC2209_Circuit_v11.sch, TMC2209_Circuit_v30.brd]
2025-04-24 Uploaded gimbal 3D model files
    [Gimbal Base v8.step, Joystick cage v3.step, Upper Assembly v18.step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]
2025-04-24 Rename Wiring Diagram.jpg to WiringDiagram.jpg

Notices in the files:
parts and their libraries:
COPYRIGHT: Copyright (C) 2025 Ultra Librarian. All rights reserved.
